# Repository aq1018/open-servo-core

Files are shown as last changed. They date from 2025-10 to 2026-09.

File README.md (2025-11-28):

# open-servo-core

Democratize Robotics For Everyone

## Overview

This project aims to create a drop-in replacement control board for MG90-class servos that adds cascade control, current sensing, and a DYNAMIXEL-style serial protocol. The goal is to make robotics more accessible by turning a $2.50 servo into a $5 smart actuator (vs $30+ for commercial alternatives). Built with bare-metal Rust on CH32V microcontrollers.

## Project Status

🚧 **Early Development** - Not ready for general use

- ✅ **Working**: Basic PID control, PWM motor drive, current sensing, ADC readings
- 🔄 **In Progress**: Cascade control loops, UART protocol implementation  
- 📋 **Planned**: System identification, auto-tuning, multi-servo bus communication

## Project Structure

```
firmware/open-servo-core/  - Rust firmware for CH32V
hardware/
  servo-dev-board/         - Development board for firmware testing  
  encoder-board/           - Quadrature IR sensor board for system ID
  motor-mount/             - Test fixtures and mechanical designs
  common/                  - Shared KiCad symbols & footprints
```

## Development

- **Firmware**: Bare-metal Rust using PAC-level drivers, debugged with probe-rs and defmt
- **Hardware**: KiCad designs with JLCPCB production files available
- **Target MCU**: CH32V003 (RISC-V, ultra low-cost)
- **Control**: Cascaded loops - current → velocity → position

## Goals

- Implement cascade control with inner current, middle velocity, and outer position loops
- Create a DYNAMIXEL-inspired protocol for controlling multiple servos on one bus
- Add system identification and auto-tuning capabilities
- Keep total cost under $5 per modified servo
- Require no mechanical modifications to the servo

## Contributing

This is experimental research code in active development. Issues and discussions are welcome. Check the hardware folders for KiCad designs and the firmware folder for the Rust implementation.

## License

MIT License - See [LICENSE](LICENSE) file for details

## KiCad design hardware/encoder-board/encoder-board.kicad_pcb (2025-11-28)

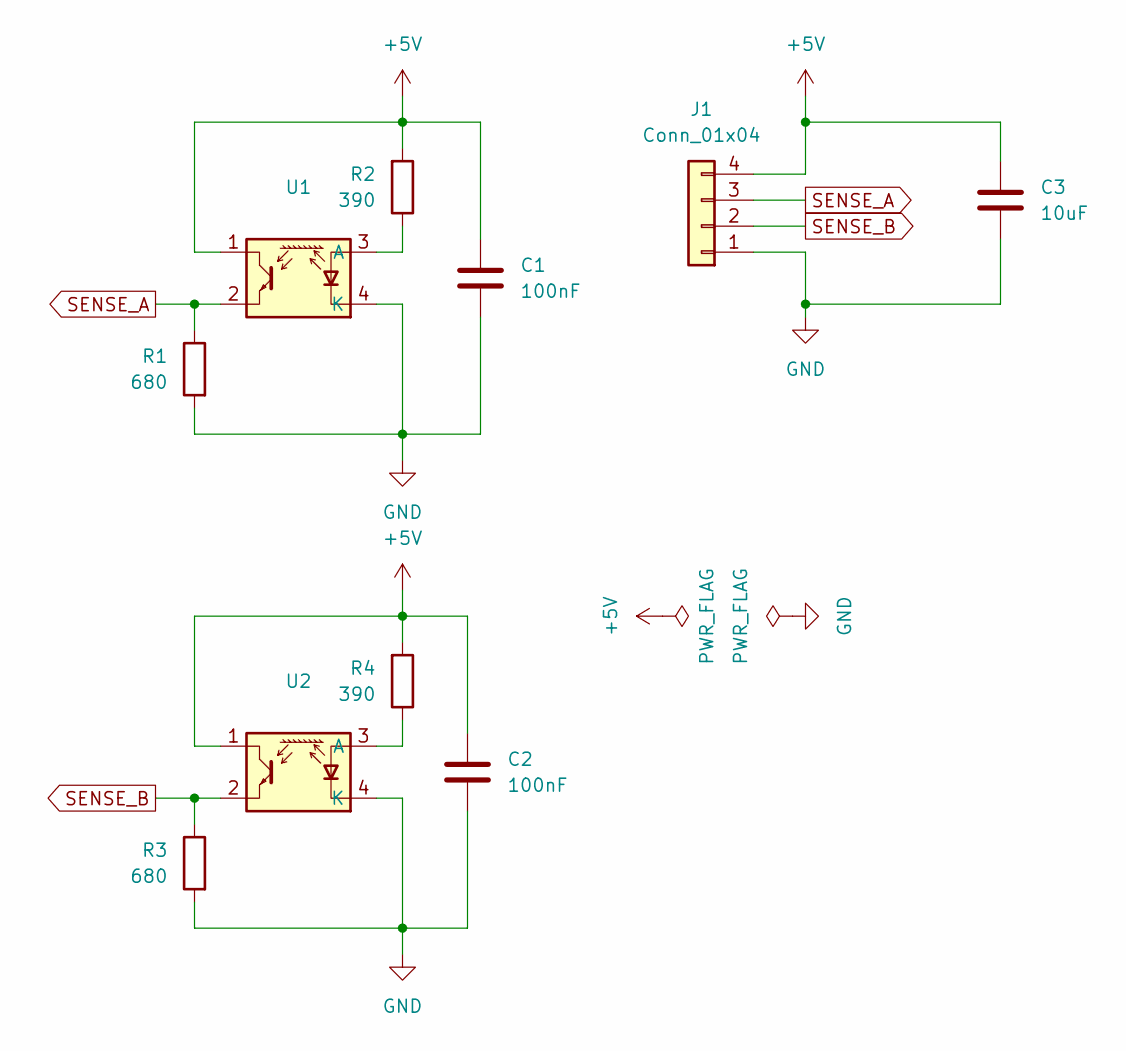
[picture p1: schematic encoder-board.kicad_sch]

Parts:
C1, C2: 100nF; C_0805_2012Metric_Pad1.18x1.45mm_HandSolder
C3: 10uF; C_0805_2012Metric_Pad1.18x1.45mm_HandSolder
J1: Conn_01x04; PinHeader_1x04_P2.54mm_Vertical; LCSC C780062
R1, R3: 680; R_0805_2012Metric_Pad1.20x1.40mm_HandSolder; LCSC C22548
R2, R4: 390; R_0805_2012Metric_Pad1.20x1.40mm_HandSolder; LCSC C125923
U1, U2: ITR1204SR10A_TR(BY); OPTO-SMD-4_ITR1204SR10A; LCSC C475373

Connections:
+5V: C1.1, C2.1, C3.1, J1.4, R2.2, R4.2, U1.1, U2.1
GND: C1.2, C2.2, C3.2, J1.1, R1.2, R3.2, U1.4 (K), U2.4 (K)
unnamed: R2.1, U1.3 (A)
unnamed: R4.1, U2.3 (A)
SENSE_A: J1.3, R1.1, U1.2
SENSE_B: J1.2, R3.1, U2.2

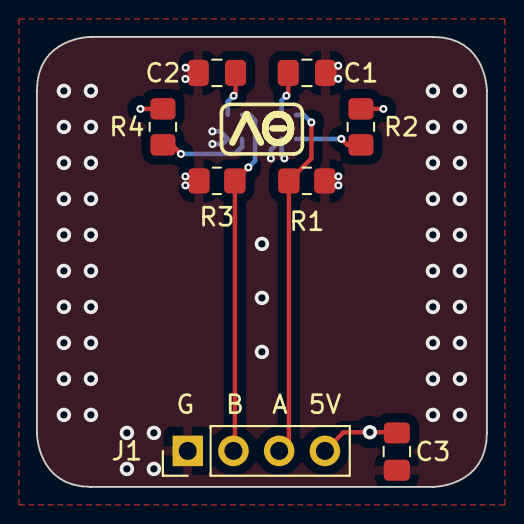
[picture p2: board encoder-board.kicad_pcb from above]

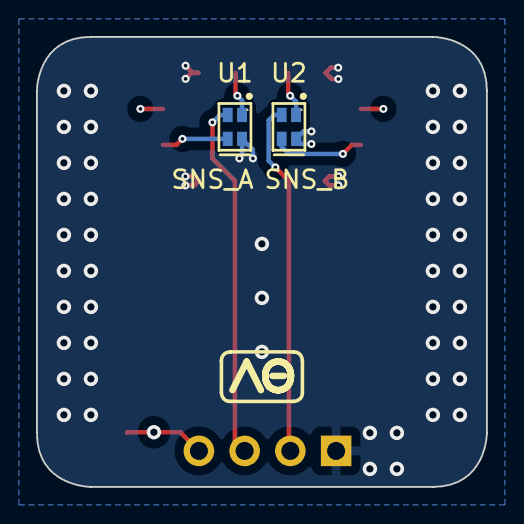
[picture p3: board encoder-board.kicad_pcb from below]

Board: 4 copper layers, 25.0 x 25.0 mm, 10 parts (2 on the bottom side), 6 nets.

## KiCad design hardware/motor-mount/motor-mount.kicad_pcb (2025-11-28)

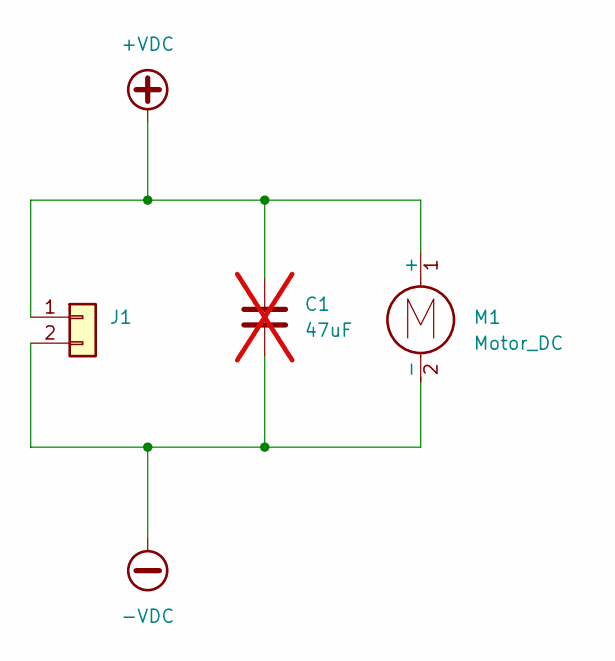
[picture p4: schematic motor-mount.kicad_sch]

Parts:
C1: 47uF; C_1206_3216Metric; not fitted
J1: PinHeader_1x02_P2.54mm_Vertical
M1: Motor_DC; SG90_Motor

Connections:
+VDC: C1.1, J1.1, M1.1 (+)
-VDC: C1.2, J1.2, M1.2 (-)

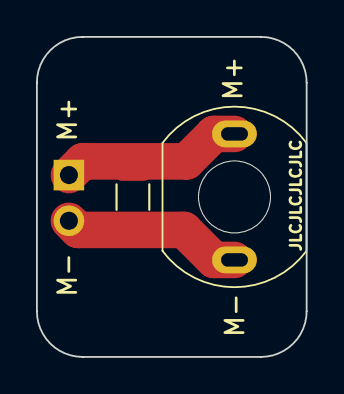
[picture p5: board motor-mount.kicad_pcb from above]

Board: 2 copper layers, 15.0 x 17.8 mm, 3 parts (1 on the bottom side), 2 nets.

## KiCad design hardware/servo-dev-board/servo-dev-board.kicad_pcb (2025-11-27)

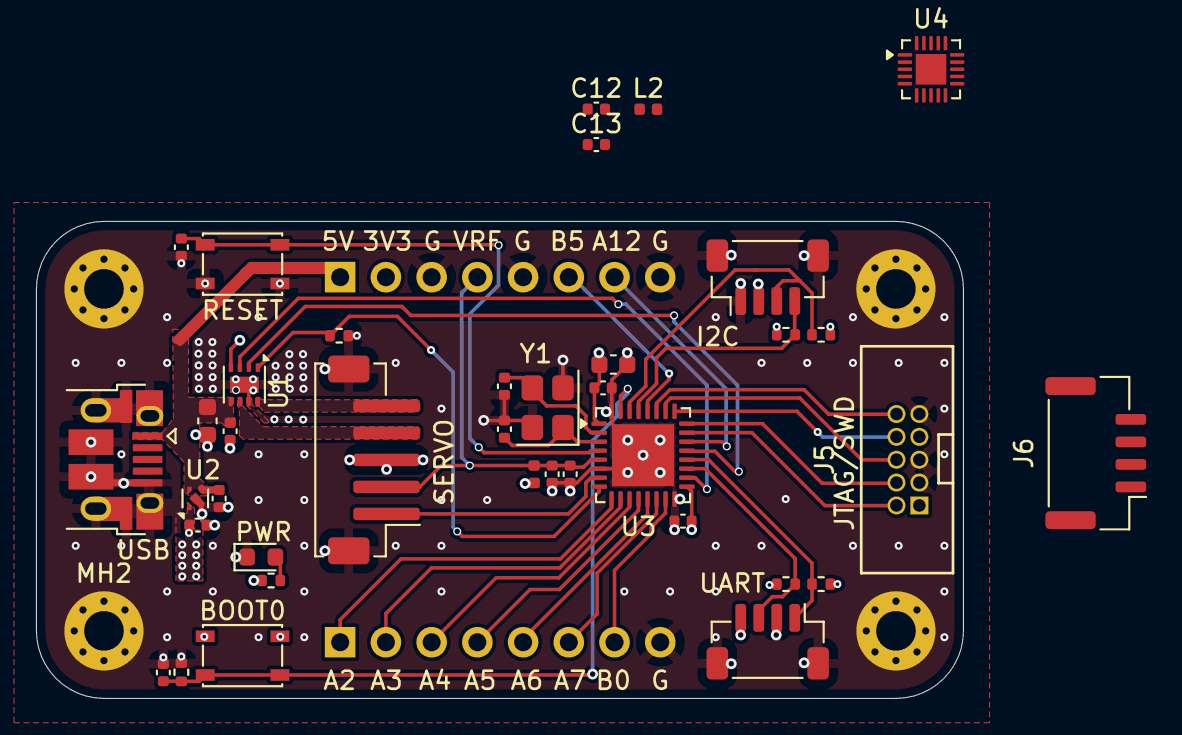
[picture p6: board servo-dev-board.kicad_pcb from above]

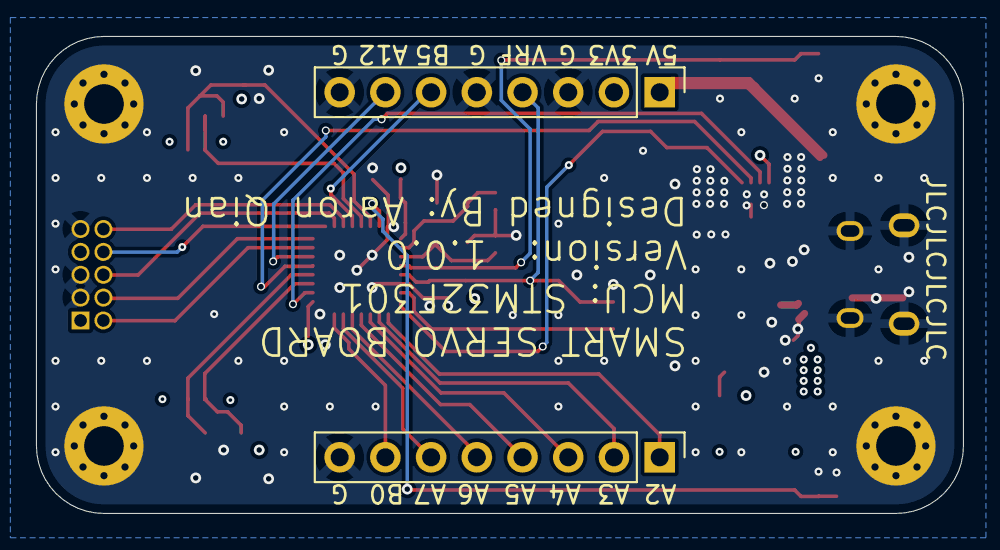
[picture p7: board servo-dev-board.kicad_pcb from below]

Board: 4 copper layers, 51.5 x 26.5 mm, 44 parts (2 on the bottom side), 34 nets.

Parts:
C1, C2, C3, C6, C7, C13: 0.1uF; C_0402_1005Metric
C4, C5, C10: 1uF; C_0402_1005Metric
C8: 4.7uF; C_0603_1608Metric
C9: 10nF; C_0402_1005Metric
C11: 22uF; C_0603_1608Metric
C12: 10uF; C_0402_1005Metric
CL1, CL2: 12pF; C_0402_1005Metric
H1, H2: Conn_01x08_Pin; PinHeader_1x08_P2.54mm_Vertical
J1: USB_B_Micro; USB_Micro-B_Amphenol_10103594-0001LF_Horizontal
J2: Conn_01x05_MountingPin; JST_ZH_B5B-ZR-SM4-TF_1x05-1MP_P1.50mm_Vertical
J3, J4: Conn_01x04_MountingPin; JST_SH_BM04B-SRSS-TB_1x04-1MP_P1.00mm_Vertical
J5: Conn_02x05_Odd_Even; IDC-TH_10P-P1.27-X1270WV-2X05A-6TV01
J6: Conn_01x04_MountingPin; JST_GH_BM04B-GHS-TBT_1x04-1MP_P1.25mm_Vertical
L1, L2: 1kΩ@100Mhz; L_0402_1005Metric
LED1: RED; LED_0603_1608Metric
MH1, MH2, MH3, MH4: MountingHole_Pad_MP; MountingHole_2.2mm_M2_Pad_Via
R1, R2, R3, R4, R5, R6: 4K7; R_0402_1005Metric
R7: 1K5; R_0402_1005Metric
SW1, SW2: SW_Push; SW_SPST_PTS810
U1: DRV8231ADSGR; WSON-8-1EP_2x2mm_P0.5mm_EP0.9x1.6mm
U2: SSP7615-33DFR; UDFN-4-1EP_1x1mm_P0.65mm_EP0.48x0.48mm
U3: STM32F301K8Ux; QFN-32-1EP_5x5mm_P0.5mm_EP3.45x3.45mm
U4: CH32V006F8U6; UQFN-20-1EP_3x3mm_P0.4mm_EP1.7x1.7mm
Y1: 16MHz 9pF; Crystal_SMD_3225-4Pin_3.2x2.5mm

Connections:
+3V3: C4.2, C6.2, C7.2, C8.2, H2.2, J3.2, J4.4, J5.1, L1.2, R1.2, R2.1, R3.1, R4.2, R5.1, SW2.1, U1.4 (VREF), U2.1 (VOUT), U3.1 (VDD), U3.17 (VDD)
+5V: C1.2, C5.2, C11.2, C12.2, H2.1, J1.1 (VBUS), J6.1, L2.1, U1.5 (VM), U2.3 (EN), U2.4 (VIN)
/+5V_TRX: C13.2, L2.2
/BOOT0: C3.1, R6.1, SW2.2, U3.31 (BOOT0)
/I2C1_SCL: J3.4, R3.2, U3.29 (PB6)
/I2C1_SDA: J3.3, R2.2, U3.30 (PB7)
/ISNS: R7.1, U1.1 (IPROPI), U3.8 (PA1)
/JTCK_SWCLK: J5.4, U3.24 (PA14)
/JTDI: J5.8, U3.25 (PA15)
/JTDO_SWO: J5.6, U3.26 (PB3)
/JTMS_SWDIO: J5.2, U3.23 (PA13)
/M1: J2.4, U1.6 (OUT1)
/M2: J2.5, U1.8 (OUT2)
/NJTRST: J5.10, U3.27 (PB4)
/NRST: C2.2, SW1.1, U3.4 (NRST), U4.1 (PD7/RST/T2C4/OPP1/PA4/U2TX_/OPN2)
/OSC+: CL1.1, U3.3 (PF1), Y1.1
/OSC-: CL2.2, U3.2 (PF0), Y1.3
/PA2: H1.1, U3.9 (PA2)
/PA3: H1.2, U3.10 (PA3)
/PA4: H1.3, U3.11 (PA4)
/PA5: H1.4, U3.12 (PA5)
/PA6: H1.5, U3.13 (PA6)
/PA7: H1.6, U3.14 (PA7)
/PA12: H2.7, U3.22 (PA12)
/PB0: H1.7, U3.15 (PB0)
/PB5: H2.6, U3.28 (PB5)
/POT: J2.1, U3.7 (PA0), U4.17 (PD3/T1/T2/U2RX_/NSS_/OPP2/A4)
/PWM1: U1.3 (IN1), U3.18 (PA8)
/PWM2: U1.2 (IN2), U3.21 (PA11)
/UART1_RX: J4.1, R1.1, U3.20 (PA10), U4.20 (PD6/T2/RX/TX_/MOSI_/A6)
/UART1_TX: J4.3, R4.1, U3.19 (PA9), U4.19 (PD5/T2/TX/RX_/MISO_/A5)
/VREF: C9.2, C10.2, H2.4, J2.2, L1.1, U3.5 (VDDA)
GND: C1.1, C2.1, C3.2, C4.1, C5.1, C6.1, C7.1, C8.1, C9.1, C10.1, C11.1, C12.1, C13.1, CL1.2, CL2.1, H1.8, H2.3, H2.5, H2.8, J1.5 (GND), J1.6 (Shield), J2.3, J2.MP (MountPin), J3.1, J3.MP (MountPin), J4.2, J4.MP (MountPin), J5.3, J5.5, J5.9, J6.2, LED1.1 (K), R6.2, R7.2, SW1.2, U1.7 (GND), U1.9 (EP), U2.2 (GND), U2.5 (EP), U3.6 (VSSA), U3.16 (VSS), U3.32 (VSS), U3.33 (VSS), U4.4 (VSS), U4.21 (VSS), Y1.2, Y1.4
unnamed: LED1.2 (A), R5.2

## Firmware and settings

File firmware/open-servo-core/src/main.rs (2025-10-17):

#![no_main]
#![no_std]

use defmt_rtt as _;
use panic_probe as _;

use core::cell::RefCell;
use cortex_m::{
    asm,
    interrupt::{free, Mutex},
};
use cortex_m_rt::entry;
use pid::Pid;
use stm32f3::stm32f301 as pac;

use pac::interrupt;

#[derive(Copy, Clone, defmt::Format)]
struct SystemState {
    // Desired Servo Position
    pub setpoint: u16,

    // Current Servo Position
    pub position: u16,

    // PWM Duty Cycle
    pub pwm_duty: i32,

    // Current in mA
    pub current: f32,

    // VDDA Voltage
    pub vdda: f32,

    // Chip Temperature in Celsius
    pub temperature: f32,
}

impl SystemState {
    fn new() -> Self {
        SystemState {
            setpoint: 0,
            position: 0,
            pwm_duty: 0,
            current: 0.0,
            vdda: 0.0,
            temperature: 0.0,
        }
    }
}

const VREFINT_CAL_ADDR: u32 = 0x1FFFF7BA;
const TS_CAL1_ADDR: u32 = 0x1FFFF7B8;
const TS_CAL2_ADDR: u32 = 0x1FFFF7C2;

// RCC parameters
// const RCC_HSE_CLOCK_HZ: u32 = 16_000_000;
const RCC_SYSCLK_HZ: u32 = 72_000_000;

// ADC parameters
const ADC_MAX_VALUE: f32 = 4095.0; // 12-bit ADC

// Current sense parameters
const ISENSE_AIPROPI: f32 = 1500.0; // uA/A
const ISENSE_RESISTOR_OHM: f32 = 2200.0; // Ohm
const ISENSE_FACTOR: f32 = ISENSE_AIPROPI / ISENSE_RESISTOR_OHM; // uA / V

// PWM parameters
const PWM_FREQUENCY: u32 = 20_000;
const PWM_MAX_DUTY: u16 = ((RCC_SYSCLK_HZ / PWM_FREQUENCY / 2) - 1) as u16;
const PWM_REVERSE: bool = false;

// PID controller parameters
const PID_KP: f32 = 40.0;
const PID_KI: f32 = 0.0;
const PID_KD: f32 = 0.0;
const PID_KP_MAX: f32 = PWM_MAX_DUTY as f32;
const PID_KI_MAX: f32 = PWM_MAX_DUTY as f32 * 0.8;
const PID_KD_MAX: f32 = PWM_MAX_DUTY as f32 * 0.8;
const PID_OUTPUT_MAX: f32 = PWM_MAX_DUTY as f32;

static ADC_DATA: Mutex<RefCell<Option<&[u16; 5]>>> = Mutex::new(RefCell::new(Option::None));
static PID_CONTROLLER: Mutex<RefCell<Option<Pid<f32>>>> = Mutex::new(RefCell::new(Option::None));
static SYSTEM_STATE: Mutex<RefCell<Option<SystemState>>> = Mutex::new(RefCell::new(Option::None));

#[entry]
fn main() -> ! {
    let p = pac::Peripherals::take().unwrap();

    init_rcc(&p);
    init_tim1_pwm(&p);
    init_tim2_counter(&p);
    init_led(&p);
    init_dma(&p);
    init_adc(&p);

    // intialize PID controller
    let mut pid: Pid<f32> = Pid::new(0.0, PID_OUTPUT_MAX);
    pid.p(PID_KP, PID_KP_MAX);
    pid.i(PID_KI, PID_KI_MAX);
    pid.d(PID_KD, PID_KD_MAX);
    free(|cs| PID_CONTROLLER.borrow(cs).replace(Some(pid)));

    // initialize system state
    let system_state = SystemState::new();
    free(|cs| SYSTEM_STATE.borrow(cs).replace(Some(system_state)));

    // enable interrupts
    unsafe {
        pac::NVIC::unmask(pac::Interrupt::TIM2);
        pac::NVIC::unmask(pac::Interrupt::DMA1_CH1);
    }

    defmt::info!("Initialized");

    // start ADC conversion
    p.ADC1.cr.modify(|_, w| w.adstart().start_conversion());

    loop {}
}

// interrupt handler for TIM2
#[interrupt]
fn TIM2() {
    defmt::info!("TIM2 interrupt");

    // toggle PA3
    unsafe {
        (*pac::GPIOA::ptr())
            .odr
            .modify(|r, w| w.odr3().bit(!r.odr3().bit()));
    }

    // clone system state to local variable
    let system_state = free(|cs| SYSTEM_STATE.borrow(cs).borrow().unwrap());
    defmt::info!("{}", system_state);

    // clear interrupt flag
    unsafe {
        (*pac::TIM2::ptr()).sr.modify(|_, w| w.uif().clear());
    }
}

#[interrupt]
fn DMA1_CH1() {
    let dma1 = unsafe { &(*pac::DMA1::ptr()) };
    let [is_complete, is_error] = cortex_m::interrupt::free(|_| {
        [
            dma1.isr.read().tcif1().is_complete(),
            dma1.isr.read().teif1().is_error(),
        ]
    });

    // check interrupt flag for transfer complete
    if !is_complete {
        defmt::info!("Transfer complete interrupt flag not set");
        return;
    }

    // check interrupt flag for transfer error
    if is_error {
        defmt::error!("Transfer error interrupt flag set");
        return;
    }

    // clone ADC_DATA to local variable
    let [vref, pot, isns, mut setpoint, temp] =
        free(|cs| ADC_DATA.borrow(cs).borrow().unwrap().clone());

    // hardcode for now
    setpoint = 2048;

    // calculate pwm duty cycle using PID controller
    let pid_output = free(|cs| {
        let mut pid_option = PID_CONTROLLER.borrow(cs).borrow_mut();
        let pid = pid_option.as_mut().unwrap();
        pid.setpoint(setpoint).next_control_output(pot as f32)
    });
    let mut duty: i32 = pid_output.output as i32;
    if PWM_REVERSE {
        duty = duty * -1;
    }

    // set PWM duty cycle
    let tim1 = unsafe { &(*pac::TIM1::ptr()) };
    if duty > 0 {
        let duty: u16 = duty as u16;

        tim1.ccr1().write(|w| w.ccr().bits(duty));
        tim1.ccr4().write(|w| w.ccr().bits(0));
    } else {
        let duty: u16 = (duty * -1) as u16;

        tim1.ccr1().write(|w| w.ccr().bits(0));
        tim1.ccr4().write(|w| w.ccr().bits(duty));
    }

    // convert ADC values to physical values
    let vdda = convert_vdda(vref);
    let temp = convert_temperature(temp, vdda);
    let current = convert_current(isns, vdda);

    // update system state
    free(|cs| {
        let mut system_state_options = SYSTEM_STATE.borrow(cs).borrow_mut();
        let system_state = system_state_options.as_mut().unwrap();

        system_state.setpoint = setpoint;
        system_state.position = pot;
        system_state.pwm_duty = duty;
        system_state.vdda = vdda;
        system_state.current = current;
        system_state.temperature = temp;
    });

    // clear interrupt flag
    unsafe {
        (*pac::DMA1::ptr()).ifcr.write(|w| w.cgif1().set_bit());
    }
}

fn convert_temperature(adc_value: u16, vdda_value: f32) -> f32 {
    let ts_cal1: u16 = unsafe { core::ptr::read(TS_CAL1_ADDR as *const u16) };
    let ts_cal2: u16 = unsafe { core::ptr::read(TS_CAL2_ADDR as *const u16) };
    let ts_cal1_temp: f32 = 30.0;
    let ts_cal2_temp: f32 = 110.0;
    let ts_cal1_voltage: f32 = 3.3 * ts_cal1 as f32 / ADC_MAX_VALUE;
    let ts_cal2_voltage: f32 = 3.3 * ts_cal2 as f32 / ADC_MAX_VALUE;
    let ts_slope: f32 = (ts_cal2_temp - ts_cal1_temp) / (ts_cal2_voltage - ts_cal1_voltage);
    let ts_offset: f32 = ts_cal1_temp - ts_slope * ts_cal1_voltage;
    let temp_voltage = vdda_value * adc_value as f32 / ADC_MAX_VALUE;
    let temp = ts_slope * temp_voltage + ts_offset;
    return temp;
}

fn convert_vdda(adc_value: u16) -> f32 {
    let vrefint_cal: u16 = unsafe { core::ptr::read(VREFINT_CAL_ADDR as *const u16) };
    let vdda = 3.3 * vrefint_cal as f32 / adc_value as f32;
    return vdda;
}

fn convert_voltage(adc_value: u16, vdda_value: f32) -> f32 {
    vdda_value * adc_value as f32 / ADC_MAX_VALUE
}

fn convert_current(adc_value: u16, vdda_value: f32) -> f32 {
    let isense_voltage = convert_voltage(adc_value, vdda_value);
    let current = isense_voltage * ISENSE_FACTOR / 1000.0; // convert uA to mA
    return current;
}

fn init_dma(p: &pac::Peripherals) {
    // enable DMA1 Channel 1
    p.DMA1.ch1.cr.modify(|_, w| {
        w.pl()
            .low() // low priority
            .circ()
            .enabled() // enable circular mode
            .dir()
            .from_peripheral() // read from peripheral
            .msize()
            .bits16() // 16 bit memory size
            .psize()
            .bits16() // 16 bit peripheral size
            .tcie()
            .enabled() // enable transfer complete interrupt
            .teie()
            .enabled() // enable transfer error interrupt
            .mem2mem()
            .disabled() // memory to memory mode disabled
            .minc()
            .enabled() // increment memory address
            .pinc()
            .disabled() // do not increment peripheral address
    });

    p.DMA1
        .ch1
        .par
        .write(|w| unsafe { w.bits(p.ADC1.dr.as_ptr() as u32) }); // set peripheral address to ADC1_DR

    let adc_data = cortex_m::singleton!(: [u16; 5] = [0; 5]).unwrap();
    p.DMA1
        .ch1
        .mar
        .write(|w| unsafe { w.bits(adc_data.as_ptr() as u32) }); // set memory address to ADC_DATA

    free(|cs| ADC_DATA.borrow(cs).replace(Some(adc_data)));

    // set number of data to transfer to 5 because we are converting 5 channels
    p.DMA1.ch1.ndtr.write(|w| w.ndt().bits(5));

    // enable DMA1 Channel 1
    p.DMA1.ch1.cr.modify(|_, w| w.en().enabled());
}

fn init_adc(p: &pac::Peripherals) {
    let adc1 = &p.ADC1;

    /*
     * Configure ADC
     */
    p.ADC1_2.ccr.modify(|_, w| {
        w.ckmode()
            .sync_div1() // use synchronous clock mode
            .tsen()
            .enabled() // enable temperature sensor
            .vrefen()
            .enabled() // enable VREFINT
    });

    adc1.cfgr.modify(|_, w| {
        w.res()
            .bits12() // set ADC to 12 bit resolution
            .align()
            .right() // set ADC to right aligned
            .cont()
            .single() // set ADC to single conversion mode
            .discen()
            .disabled() // set ADC to disable discontinuous mode
            .dmacfg()
            .circular() // set ADC to circular DMA mode
            .dmaen()
            .enabled() // enable DMA
            .ovrmod()
            .preserve() // set ADC to preserve overrun
            .exten()
            .rising_edge() // set ADC to rising edge trigger
            .extsel()
            .tim1_trgo2() // set ADC to TIM1_TRGO2
    });

    /*
     * ADC calibration
     */
    // enable internal voltage regulator
    adc1.cr.modify(|_, w| w.advregen().intermediate());
    adc1.cr.modify(|_, w| w.advregen().enabled());
    // we need to wait 10 us for the voltage regulator to stabilize
    // we are running at 72 MHz, so 1 us = 72 cycles
    asm::delay(10 * 72);

    // run calibration
    adc1.cr
        .modify(|_, w| w.adcaldif().single_ended().adcal().calibration());
    while adc1.cr.read().adcal().is_calibration() {}

    // disable the internal voltage regulator, the internal analog calibration is kept
    adc1.cr.modify(|_, w| w.advregen().intermediate());
    adc1.cr.modify(|_, w| w.advregen().disabled());

    // ADEN bit cannot be set during ADCAL=1 and 4 ADC clock cycle after the ADCAL bit is
    // cleared by hardware
    // ADC clock cycle is set to be 72 MHz / 1 = 72 MHz
    asm::delay(4);

    /*
     * Configure ADC Channels
     */
    // configure PA0, PA1, PA2 as analog input
    let gpioa = &p.GPIOA;
    gpioa
        .moder
        .modify(|_, w| w.moder0().analog().moder1().analog().moder2().analog());
    gpioa.pupdr.modify(|_, w| {
        w.pupdr0()
            .floating()
            .pupdr1()
            .floating()
            .pupdr2()
            .floating()
    });

    // configure channels for conversion
    adc1.sqr1.modify(|_, w| unsafe {
        w.l()
            .bits(4) // set number of conversions to 5, this register counts from 0
            .sq1()
            .bits(18) // set vrefint ( ch 18 ) as first conversion
            .sq2()
            .bits(1) // set PA0 ( ch 1 )  as second conversion
            .sq3()
            .bits(2) // set PA1 ( ch 2 )  as third conversion
            .sq4()
            .bits(3) // set PA2 ( ch 3 ) as fourth conversion
    });

    adc1.sqr2.modify(|_, w| unsafe {
        w.sq5().bits(16) // set tempature sensor ( ch 16 ) as first conversion
    });

    // set sample time for channels
    adc1.smpr1.modify(|_, w| {
        w.smp1()
            .cycles181_5() // PA0
            .smp2()
            .cycles181_5() // PA1
            .smp3()
            .cycles181_5() // PA2
    });

    adc1.smpr2.modify(|_, w| {
        w.smp16()
            .cycles181_5() // VREFINT
            .smp18()
            .cycles181_5() // Temperature sensor
    });

    /*
     * ENABLE ADC
     */
    adc1.cr.modify(|_, w| w.aden().enabled());
    while adc1.isr.read().adrdy().is_not_ready() {}
}

fn init_led(p: &pac::Peripherals) {
    let gpioa = &p.GPIOA;

    // configure PA3 as output
    gpioa.moder.modify(|_, w| w.moder3().output());

    // configure PA3 as push-pull
    gpioa.otyper.modify(|_, w| w.ot3().push_pull());

    // configure PA3 as high speed output
    gpioa.ospeedr.modify(|_, w| w.ospeedr3().high_speed());

    // configure PA3 as no pull-up, no pull-down
    gpioa.pupdr.modify(|_, w| w.pupdr3().floating());

    // set PA3 to low
    gpioa.odr.modify(|_, w| w.odr3().low());
}

fn init_tim2_counter(p: &pac::Peripherals) {
    let tim2 = &p.TIM2;

    // set prescaler to 72, so that the counter will increment every 1 us
    tim2.psc.write(|w| w.psc().bits(72));

    // set auto-reload register to 100_000, so that the counter will overflow every 0.1 second
    tim2.arr.write(|w| unsafe { w.arr().bits(100_000) });

    // generate an update event to load the prescaler value to the counter
    tim2.egr.write(|w| w.ug().update());

    // enable update interrupt
    tim2.dier.write(|w| w.uie().enabled());

    // enable TIM2
    tim2.cr1.write(|w| w.cen().enabled());
}

fn init_tim1_pwm(p: &pac::Peripherals) {
    let tim1 = &p.TIM1;

    // Enable auto-reload preload
    tim1.cr1.modify(|_, w| w.arpe().enabled());

    // set pwm mode to center aligned count up
    tim1.cr1.modify(|_, w| w.cms().center_aligned1().dir().up());

    // set PWM frequency to 10 kHz center aligned ( 20 KHz PWM frequency)
    tim1.arr.write(|w| w.arr().bits(3599)); // 72 MHz / 3600 = 20 kHz
    tim1.psc.write(|w| w.psc().bits(0)); // 72 MHz / 1 = 72 MHz

    // generate an update event to load the prescaler value to the counter
    tim1.egr.write(|w| w.ug().update());

    // enable main output enable
    tim1.bdtr.modify(|_, w| w.moe().enabled());

    // set trigger output to output compare 2 (OC3REF)
    // this is used to trigger ADC conversions
    tim1.cr2.modify(|_, w| unsafe {
        // See STM32F301 Reference Manual section 17.4.2.
        // MMS2 register is used to trigger ADC conversions
        w.mms2().bits(0b0110) // OC3REF
    });

    // enable TIM1
    tim1.cr1.modify(|_, w| w.cen().enabled());

    init_tim1_pwm_channels(p);
}

fn init_tim1_pwm_channels(p: &pac::Peripherals) {
    let gpioa = &p.GPIOA;
    let tim1 = &p.TIM1;

    // configure PA8 ( channel 1 ) as PWM output
    {
        // configure PA8 as alternate function
        gpioa.moder.modify(|_, w| w.moder8().alternate());

        // set PA8 alternate function map to TIM1_CH1 ( AF6 )
        gpioa.afrh.modify(|_, w| w.afrh8().af6());

        // configure PA8 as high speed output
        gpioa.ospeedr.modify(|_, w| w.ospeedr8().high_speed());

        // configure PA8 as push-pull
        gpioa.otyper.modify(|_, w| w.ot8().push_pull());

        // configure PA8 as pull down
        gpioa.pupdr.modify(|_, w| w.pupdr8().pull_down());

        // configure Channel 1 as PWM mode 1 and enable preload register
        tim1.ccmr1_output().modify(|_, w| {
            w.oc1pe()
                .enabled() // enable preload register for Channel 1
                .oc1m()
                .pwm_mode1() // PWM mode 1 for Channel 1
        });

        // set PWM duty cycle to 0
        tim1.ccr1().write(|w| w.ccr().bits(0));

        // enable PWM output
        tim1.ccer.write(|w| w.cc1e().set_bit());
    }

    // configure TIM channel 3 to PWM output
    {
        // configure TIM1 as output compare and enable preload register
        tim1.ccmr2_output().modify(|_, w| {
            w.oc3pe()
                .enabled() // enable preload register for Channel 3
                .oc3m()
                .pwm_mode1() // PWM mode 1 for Channel 3
        });

        // Set CCR to center of PWM period
        tim1.ccr3().modify(|_, w| w.ccr().bits(1));

        // enable PWM output
        tim1.ccer.modify(|_, w| w.cc3e().set_bit());
    }

    // configure PA11 ( channel 4 ) as PWM output
    {
        // configure PA11 as alternate function
        gpioa.moder.modify(|_, w| w.moder11().alternate());

        // set PA11 alternate function map to TIM1_CH4 ( AF11 )
        gpioa.afrh.modify(|_, w| w.afrh11().af11());

        // configure PA11 as high speed output
        gpioa.ospeedr.modify(|_, w| w.ospeedr11().high_speed());

        // configure PA11 as push-pull
        gpioa.otyper.modify(|_, w| w.ot11().push_pull());

        // configure PA11 as pull down
        gpioa.pupdr.modify(|_, w| w.pupdr11().pull_down());

        // configure TIM1 as PWM mode 1 and enable preload register
        tim1.ccmr2_output().modify(|_, w| {
            w.oc4pe()
                .enabled() // enable preload register for Channel 4
                .oc4m()
                .pwm_mode1() // PWM mode 1 for Channel 4
        });

        // set PWM duty cycle to 0
        tim1.ccr4().modify(|_, w| w.ccr().bits(0));

        // enable PWM output
        tim1.ccer.modify(|_, w| w.cc4e().set_bit());
    }
}

fn init_rcc(p: &pac::Peripherals) {
    let rcc = &p.RCC;
    let flash = &p.FLASH;

    // enable HSI clock
    rcc.cr.modify(|_, w| w.hsion().on());
    while rcc.cr.read().hsirdy().is_not_ready() {}

    // set HSI as system clock
    rcc.cfgr.modify(|_, w| w.sw().hsi());
    while !rcc.cfgr.read().sws().is_hsi() {}

    // enable HSE clock
    rcc.cr.modify(|_, w| w.hsebyp().not_bypassed().hseon().on());
    while rcc.cr.read().hserdy().is_not_ready() {}

    // configure PLL
    rcc.cfgr2.modify(|_, w| w.prediv().div2()); // HSE is 16 MHz, so divide by 2 to get 8 MHz
    rcc.cfgr.modify(|_, w| {
        w.pllsrc()
            .hse_div_prediv() // Use HSE as PLL source
            .pllmul()
            .mul9() // 8 MHz * 9 = 72 MHz
    });

    // enable PLL
    rcc.cr.modify(|_, w| w.pllon().on());
    while rcc.cr.read().pllrdy().is_not_ready() {}

    // set Flash latency to 2 wait states since we're running at 72 MHz
    flash.acr.write(|w| w.latency().ws2());

    // set AHB prescaler
    rcc.cfgr.modify(|_, w| {
        w.hpre()
            .div1() // AHB is 72 MHz
            .mcopre()
            .div1() // MCO is 72 MHz
            .ppre1()
            .div2() // APB1 is 36 MHz
            .ppre2()
            .div1() // APB2 is 72 MHz
    });

    // Wait for the new prescalers to kick in
    // "The clocks are divided with the new prescaler factor from
    //  1 to 16 AHB cycles after write"
    cortex_m::asm::delay(16);

    // switch to PLL
    rcc.cfgr.modify(|_, w| w.sw().pll());
    while !rcc.cfgr.read().sws().is_pll() {}

    // disable HSI
    rcc.cr.modify(|_, w| w.hsion().off());
    while rcc.cr.read().hsirdy().is_ready() {}

    // reset and enable Power Control
    // Enables access to the PWR_CR register
    // rcc.apb1enr.modify(|_, w| w.pwren().enabled());
    // rcc.apb1rstr.modify(|_, w| w.pwrrst().set_bit());
    // rcc.apb1rstr.modify(|_, w| w.pwrrst().clear_bit());

    // reset and enable System Configuration Controller
    // Enables access to the EXTI and COMP registers
    // rcc.apb2enr.modify(|_, w| w.syscfgen().enabled());
    // rcc.apb2rstr.modify(|_, w| w.syscfgrst().set_bit());
    // rcc.apb2rstr.modify(|_, w| w.syscfgrst().clear_bit());

    // enable FLITF clock
    // This provides read / write access to the Flash memory
    rcc.ahbenr.modify(|_, w| w.flitfen().enabled());

    // enable TIM1
    rcc.apb2enr.modify(|_, w| w.tim1en().enabled());
    rcc.apb2rstr.modify(|_, w| w.tim1rst().set_bit());
    rcc.apb2rstr.modify(|_, w| w.tim1rst().clear_bit());

    // enable TIM2
    rcc.apb1enr.modify(|_, w| w.tim2en().enabled());
    rcc.apb1rstr.modify(|_, w| w.tim2rst().set_bit());
    rcc.apb1rstr.modify(|_, w| w.tim2rst().clear_bit());

    // enable GPIOA, GPIOB, GPIOC
    rcc.ahbenr
        .modify(|_, w| w.iopaen().enabled().iopben().enabled().iopcen().enabled());

    // enable ADC1
    rcc.ahbenr.modify(|_, w| w.adc1en().enabled());
    rcc.ahbrstr.modify(|_, w| w.adc1rst().set_bit());
    rcc.ahbrstr.modify(|_, w| w.adc1rst().clear_bit());

    // enable DMA1
    rcc.ahbenr.modify(|_, w| w.dma1en().enabled());

    // delay for a bit to let the clocks settle
    cortex_m::asm::delay(65535);
}

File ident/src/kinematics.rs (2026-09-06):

//! Count <-> real-world-unit resolution for the calibration band. Turns the
//! endstop sweep (pos_min/max_phys, which equal the pot LUT endpoints
//! raw_min/raw_max) plus the human-supplied travel angles into the on-servo
//! `CalibKinematics` values: angle endpoints in centi-degrees and the
//! physical gear ratio. Pure math; the caller writes the encoded values to
//! the three calib regs in a later commit.

use crate::ripple;

/// Encoded kinematics, ready for the three calib regs. All-zero is the
/// firmware's "unset" sentinel.
#[derive(Copy, Clone, Debug, PartialEq, Eq)]
pub struct KinematicsResult {
    pub angle_min_cdeg: i16,
    pub angle_max_cdeg: i16,
    pub gear_ratio_centi: u16,
}

/// Degrees of output travel per pot count over the phys span. 0.0 on a
/// zero/non-finite span.
pub fn deg_per_count(
    angle_min_cdeg: i16,
    angle_max_cdeg: i16,
    pos_min_phys: i32,
    pos_max_phys: i32,
) -> f64 {
    let count_span = pos_max_phys as f64 - pos_min_phys as f64;
    if count_span == 0.0 {
        return 0.0;
    }
    let angle_span_deg = (angle_max_cdeg as f64 - angle_min_cdeg as f64) / 100.0;
    angle_span_deg / count_span
}

/// Encode the human's angle at each phys end into centi-degree endpoints.
/// angle_at_min pairs with pos_min_phys, angle_at_max with pos_max_phys.
pub fn angle_endpoints(angle_at_min_deg: f64, angle_at_max_deg: f64) -> (i16, i16) {
    (
        cdeg_saturating(angle_at_min_deg),
        cdeg_saturating(angle_at_max_deg),
    )
}

/// Physical gear ratio (motor revs per output rev) x100, saturating to u16.
/// 0 on degenerate input (zero pot speed, zero/non-finite deg/count).
pub fn gear_ratio_centi(motor_rev_s: f64, pot_omega_cps: f64, deg_per_count: f64) -> u16 {
    if pot_omega_cps == 0.0 || deg_per_count == 0.0 || !deg_per_count.is_finite() {
        return 0;
    }
    // counts per full output rev closes ripple::gear_ratio_check's relative
    // ratio to the physical one (360 deg/rev)
    let counts_per_output_rev = 360.0 / deg_per_count;
    let ratio = ripple::gear_ratio_check(motor_rev_s, pot_omega_cps, counts_per_output_rev);
    let centi = (ratio.abs() * 100.0).round();
    if !centi.is_finite() {
        return 0;
    }
    centi.min(u16::MAX as f64) as u16
}

/// Total motor revs over a FULL rail-to-rail traverse, extrapolated from a
/// partial (soft-bounded) sweep via the per-count rate: anchor-free geometry,
/// so a run turning `motor_revs_run` over `pot_disp` counts scales to the whole
/// `count_span`. 0.0 when the sweep covered no counts or the span is non-finite.
pub fn full_span_motor_revs(motor_revs_run: f64, pot_disp: f64, count_span: f64) -> f64 {
    if pot_disp > 0.0 && count_span.is_finite() {
        motor_revs_run * count_span / pot_disp
    } else {
        0.0
    }
}

/// Output travel (deg) implied by a counted gear ratio and the full-traverse
/// motor revs: `motor_revs_full * 360 / gear_ratio`. The inverse of the
/// travel-anchored gear derivation. 0.0 on a zero/non-finite gear ratio.
pub fn travel_deg_from_gear(motor_revs_full: f64, gear_ratio: f64) -> f64 {
    if gear_ratio > 0.0 && gear_ratio.is_finite() {
        motor_revs_full * 360.0 / gear_ratio
    } else {
        0.0
    }
}

/// Assemble the three encoded values from the endstop sweep and the
/// human-supplied travel angles.
pub fn resolve(
    pos_min_phys: i32,
    pos_max_phys: i32,
    angle_at_min_deg: f64,
    angle_at_max_deg: f64,
    motor_rev_s: f64,
    pot_omega_cps: f64,
) -> KinematicsResult {
    let (angle_min_cdeg, angle_max_cdeg) = angle_endpoints(angle_at_min_deg, angle_at_max_deg);
    let dpc = deg_per_count(angle_min_cdeg, angle_max_cdeg, pos_min_phys, pos_max_phys);
    KinematicsResult {
        angle_min_cdeg,
        angle_max_cdeg,
        gear_ratio_centi: gear_ratio_centi(motor_rev_s, pot_omega_cps, dpc),
    }
}

fn cdeg_saturating(deg: f64) -> i16 {
    if !deg.is_finite() {
        return 0;
    }
    (deg * 100.0)
        .round()
        .clamp(i16::MIN as f64, i16::MAX as f64) as i16
}

#[cfg(test)]
mod tests {
    use super::*;

    #[test]
    fn endpoints_and_deg_per_count_round_trip() {
        // 190 deg of travel over a 3900-count phys span
        let (lo, hi) = angle_endpoints(0.0, 190.0);
        assert_eq!((lo, hi), (0, 19000));
        let dpc = deg_per_count(lo, hi, 100, 4000);
        assert!((dpc - 190.0 / 3900.0).abs() < 1e-12, "dpc {dpc}");
    }

    #[test]
    fn cdeg_rounds_and_saturates() {
        assert_eq!(cdeg_saturating(12.345), 1235);
        assert_eq!(cdeg_saturating(-12.345), -1235);
        assert_eq!(cdeg_saturating(400.0), i16::MAX);
        assert_eq!(cdeg_saturating(-400.0), i16::MIN);
        assert_eq!(cdeg_saturating(f64::NAN), 0);
    }

    #[test]
    fn deg_per_count_degenerate_span_is_zero() {
        assert_eq!(deg_per_count(0, 19000, 512, 512), 0.0);
    }

    #[test]
    fn gear_ratio_from_synthetic_inputs() {
        // dpc 0.05 deg/count, pot 4000 cps -> output 0.5556 rev/s;
        // motor 83.333 rev/s implies 150:1
        let g = gear_ratio_centi(83.333_333, 4000.0, 0.05);
        assert!((g as i32 - 15000).abs() <= 1, "gear {g}");
    }

    #[test]
    fn gear_ratio_degenerate_is_zero() {
        assert_eq!(gear_ratio_centi(83.0, 0.0, 0.05), 0);
        assert_eq!(gear_ratio_centi(83.0, 4000.0, 0.0), 0);
        assert_eq!(gear_ratio_centi(83.0, 4000.0, f64::NAN), 0);
    }

    #[test]
    fn gear_ratio_saturates_to_u16() {
        assert_eq!(gear_ratio_centi(1e9, 1.0, 0.05), u16::MAX);
    }

    #[test]
    fn travel_from_gear_round_trips_through_gear_ratio_centi() {
        // gear 150, motor_revs_full 79.1667 -> travel 190 deg over a 3900-count
        // span; feeding count_span as pot speed and travel/count_span as dpc
        // recovers the gear (gear_ratio_centi = motor_revs_full*360/travel).
        let motor_revs_full = 79.166_667;
        let gear = 150.0;
        let count_span = 3900.0;
        let travel = travel_deg_from_gear(motor_revs_full, gear);
        assert!((travel - 190.0).abs() < 1e-3, "travel {travel}");
        let dpc = travel / count_span;
        let g = gear_ratio_centi(motor_revs_full, count_span, dpc);
        assert!((g as f64 / 100.0 - gear).abs() < 0.02, "gear {g}");
    }

    #[test]
    fn full_span_scales_by_count_ratio() {
        // 20 motor revs over 1000 counts of a 4000-count span -> 80 full revs
        assert!((full_span_motor_revs(20.0, 1000.0, 4000.0) - 80.0).abs() < 1e-9);
    }
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

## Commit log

2025-10-17 fix ADC voltage conversion using correct full-scale value
    Previously used PWM_MAX_DUTY (1799) instead of ADC_MAX_VALUE (4095)
    for ADC-to-voltage conversions, causing 2.28x overcurrent readings.
    Added ADC_MAX_VALUE constant and updated all ADC conversion functions.
    [main.rs]
2025-11-27 simplify encoder board to output analog output
    [encoder-board.kicad_sch]
2025-11-27 overhaul servo dev board to use ch32v00X
    [servo-dev-board.kicad_pcb, servo-dev-board.kicad_sch]
2025-11-27 remake encoder board pcb. generated jlcpcb production files.
    [encoder-board-CuBottom.gbr, encoder-board-CuIn1.gbr, encoder-board-CuIn2.gbr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]
2025-11-27 fix sensor chip 3d rendering
    [encoder-board.kicad_pcb]
2025-11-28 Rename project from open-servo-controller to open-servo-core
    - Update project name in README.md with new structure and status
    - Update firmware directory path references in VSCode and Zed settings
    - Rename firmware directory to match new project name
    - Update KiCad library references in all hardware files
    - Fix package name in Cargo.toml
    - Update 3D model paths in footprints
    [encoder-board.kicad_sch, motor-mount.kicad_pcb, motor-mount.kicad_sch]
2025-11-28 Use 'MG90-class' terminology for broader servo compatibility
    More inclusive of various MG90 servo variants
2025-11-28 Focus on CH32V microcontrollers for cost optimization
    Remove STM32 references to maintain ultra-low-cost target
2025-11-28 fix encoder board references
    [encoder-board.kicad_pcb]
2026-09-06 osc: self-describing servo calibration, counts to real-world units (#73)
    [osc-servo.json]
